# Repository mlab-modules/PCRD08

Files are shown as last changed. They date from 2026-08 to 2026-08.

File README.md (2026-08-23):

# PCRD08 - Analogue backend for SiPM detectors with scintillation crystals

Analogue front-end and ADC module for radiation detectors based on silicon photomultipliers (SiPM) coupled to scintillation crystals. The module amplifies the SiPM pulses, detects a threshold crossing, and digitizes the signal for a controlling MCU over SPI.

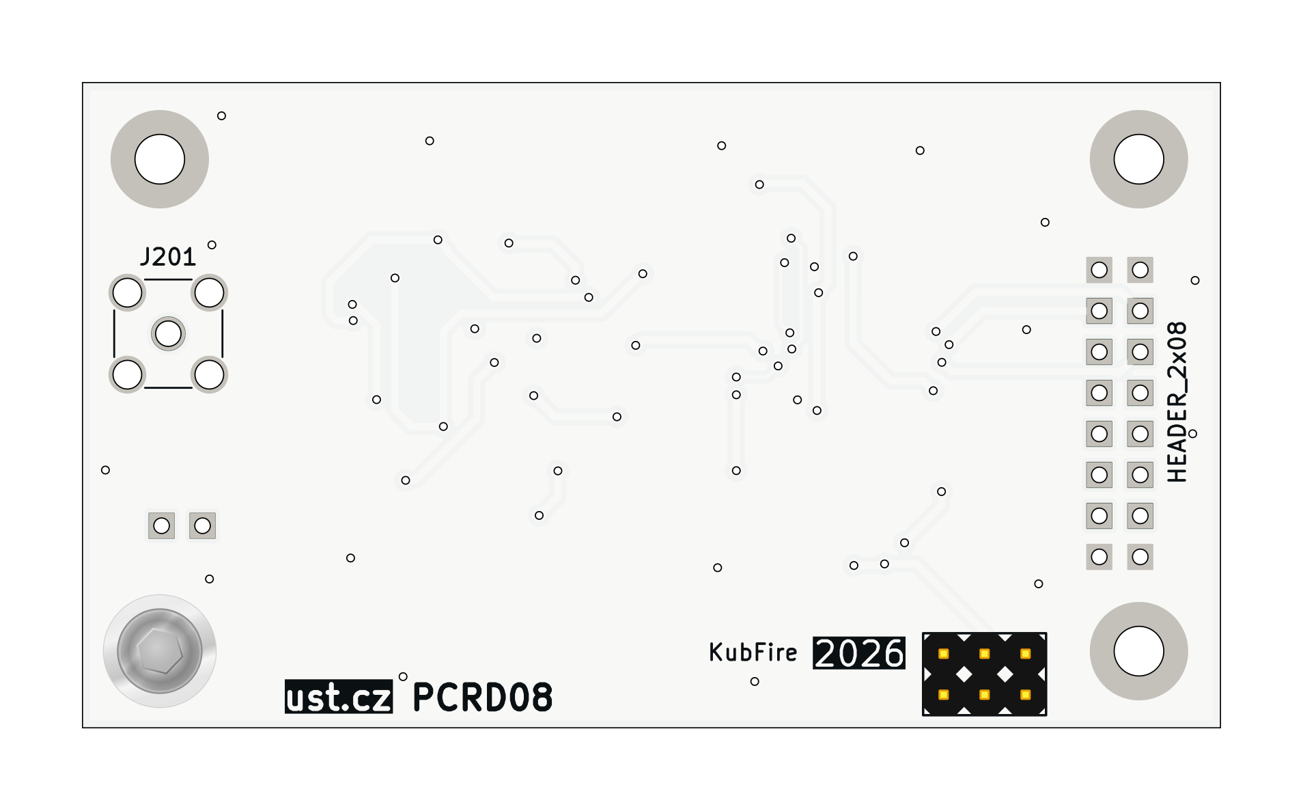
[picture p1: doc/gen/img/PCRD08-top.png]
PCRD08 Top view


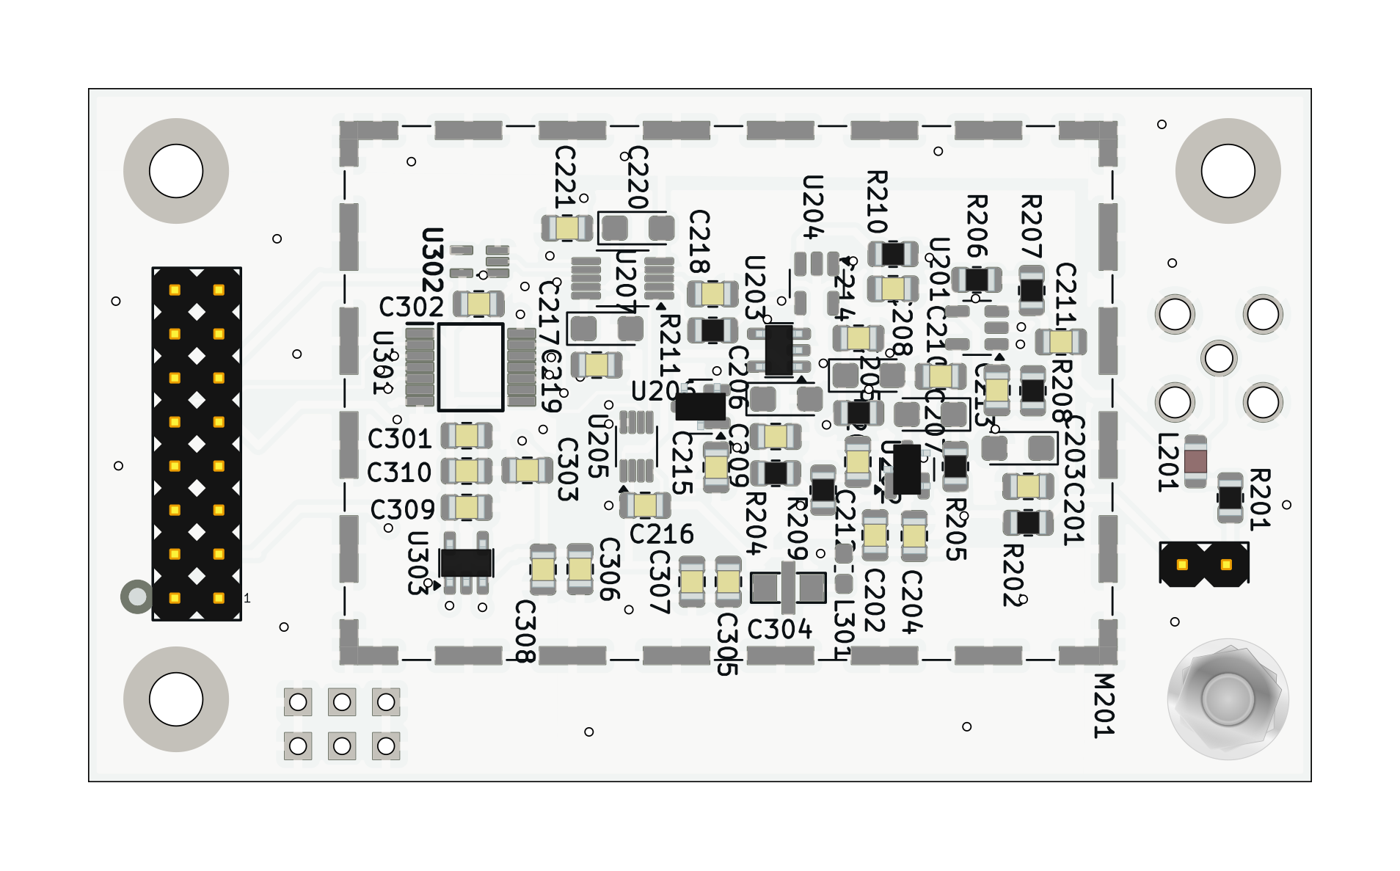
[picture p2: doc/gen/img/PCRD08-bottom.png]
PCRD08 Bottom view


### Principle of function

The detector signal enters through the MCX connector J201 and is AC-coupled into a non-inverting amplifier (U201, AD8691). A second AD8691 stage (U204) provides additional gain before the signal reaches the LTC1865-MS ADC (U207), which is read out over SPI. A comparator (U203, TS3021ILT) together with a D flip-flop (U205, SN74LVC2G74) latches a digital flag whenever the signal crosses a threshold, which the controlling MCU can use to time the ADC conversion (CONV/RST/SCK/SDI/SDO are supplied by the host over the module's socket interface).

### Difference from PCRD07

PCRD08 reuses the general architecture of the older [PCRD07](https://github.com/mlab-modules/PCRD07) analogue backend (dual AD8691 gain stages, TS3021ILT comparator, LTC1865-MS ADC), but the analogue signal processing was reworked for SiPM+scintillator pulses, which are positive-going:

- **Input polarity** - PCRD07 (both revision A and B) amplifies the input signal with an inverting first stage (signal fed into the op-amp's `-` input, gain set by the feedback/input resistor ratio). PCRD08's input stage (U201) instead feeds the signal into the op-amp's `+` input, giving a non-inverting, unity-gain-at-high-frequency response suited to positive pulses.
- **No analogue sample-and-hold switch** - PCRD07 uses an analogue switch (TS5A4594) driven by its comparator/flip-flop pair to freeze the peak voltage on a storage capacitor, i.e. a true analogue peak-detector/memory circuit. PCRD08 has no such switch or hold capacitor; its comparator/flip-flop pair (U203/U205) only produces a digital threshold-crossing flag, and the ADC conversion is triggered directly by the host rather than sampling a held analogue voltage.

(Verified by comparing `hw/sch_pcb/analogue_backend.kicad_sch` of both modules.)

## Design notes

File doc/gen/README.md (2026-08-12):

# PCB

Board size: 70.62x40.06 mm (2.78x1.58 inches)

- This is the size of the rectangle that contains the board
- Thickness: 1.6 mm (63 mils)
- Material: FR4
- Finish: HAL SnPb
- Layers: 2
- Copper thickness: 35 µm

Solder mask: TOP / BOTTOM

- Color: Green

Silk screen: TOP / BOTTOM

- Color: White

Stackup:

| Name | Type | Color | Thickness [µm]| Material | Er | Loss tan |
|---|---|---|---|---|---|---|
| F.SilkS | Top Silk Screen | | | | | |
| F.Mask | Top Solder Mask | | 10 | | | |
| F.Cu | copper | | 35 | | | |
| dielectric 1 | core | | 1510 | FR4 | 4.5 | 0.020 |
| B.Cu | copper | | 35 | | | |
| B.Mask | Bottom Solder Mask | | 10 | | | |
| B.Paste | Bottom Solder Paste  | | | | | |
| B.SilkS | Bottom Silk Screen | | | | | |

# Important sizes

Clearance: 0.2 mm (8 mils)

Track width: 0.2 mm (8 mils)

- By design rules: 0.2 mm (8 mils)

Drill: 0.5 mm (20 mils)

- Vias: 0.5 mm (20 mils) [Design: 0.4 mm (16 mils)]
- Pads: 1.0 mm (39 mils)
- The above values are real drill sizes, they add 0.1 mm (4 mils) to plated holes (PTH)

Via: 0.8/0.4 mm (31/16 mils)

- By design rules: 0.8/0.3 mm (31/12 mils)
- Micro via: yes [0.2/0.1 mm (8/4 mils)]
- Buried/blind via: yes
- Total: 58 (thru: 58 buried/blind: 0 micro: 0)

Outer Annular Ring: 0.15 mm (6 mils)

- By design rules: 0.23 mm (9 mils)

Eurocircuits class: 4B
- Using min drill 0.5 mm for an OAR of 0.15 mm

# General stats

Components count: (SMD/THT)

- Top: 0/6 (THT)
- Bottom: 56/2 (SMD + THT)

Defined tracks:

- 0.1 mm (4 mils)
- 0.2 mm (8 mils)
- 0.3 mm (12 mils)
- 0.45 mm (18 mils)
- 0.5 mm (20 mils)
- 0.6 mm (24 mils)
- 0.7 mm (28 mils)

Used tracks:

- 0.2 mm (8 mils) (82) defined: yes
- 0.45 mm (18 mils) (349) defined: yes

Defined vias:

Used vias:

- 0.8/0.4 mm (31/16 mils) (Count: 58, Aspect: 2.0 A) defined: no

Holes (excluding vias):

- 0.89 mm (35 mils) (24)
- 1.5 mm (59 mils) (1)
- 1.7 mm (67 mils) (4)
- 3.0 mm (118 mils) (4)

Oval holes:

Drill tools (including vias and computing adjusts and rounding):

- 0.5 mm (20 mils) (58)
- 1.0 mm (39 mils) (24)
- 1.6 mm (63 mils) (1)
- 1.8 mm (71 mils) (4)
- 3.1 mm (122 mils) (4)

Solder paste stats:

Using a paste with 87.75 % alloy, that has an specific gravity for the alloy of 7.4 g/cm³
and 1.0 g/cm³ for the flux. This paste has an specific gravity of  4.15 g/cm³.

The stencil thickness is  0.12 mm.

| Side | Pads with paste | Area [mm²] | Paste [g] |
|---|---|---|---|
| Total  | 184 | 265.43 | 1.32 |

Note: this is just an approximation to the theoretical value. Margins of the solder mask and waste aren't computed.

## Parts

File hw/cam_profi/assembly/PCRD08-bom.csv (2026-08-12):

Component | Description | Part | References | Value | Footprint | Quantity Per PCB | Datasheet | ust_id | ust_id2 | mf | description_1 | package | mpn | price | oc_farnell | snapeda_link | mp | supplier | oc_newark | availability | check_prices | manufacturer_name | mouser_price-stock | mouser_part_number | height | arrow_price-stock | arrow_part_number | manufacturer_part_number
1 | Unpolarized capacitor | C | C211C213C214C218 | 1nF | C_0805_2012Metric | 4 |  | 6508260b462c6d9e720541f1 651abc26462c6d9e720551fa 5c70984812875079b91f8ba6
2 | Unpolarized capacitor | C | C201C202C204C208C209C210C212C215C216C219C221C301C302C303C305C308C310 | 100nF | C_0805_2012Metric | 17 |  | 6508260b462c6d9e720541f1 5c70984712875079b91f8b4c
3 | EMI filter, single capacitor | Filter_EMI_C | C304 | 1uF | FIR_0805 | 1 | http://www.murata.com/~/media/webrenewal/support/library/catalog/products/emc/emifil/c31e.ashx?la=en-gb | 5c70984412875079b91f880f
4 | Polarized capacitor | C_Polarized | C203C205C206C207C217C220 | 10uF | CP_EIA-3216-18_Kemet-A | 6 |  | 65089dd0462c6d9e720542b3
5 | Unpolarized capacitor | C | C306C307C309 | 10uF | C_0805_2012Metric | 3 |  | 5c70984712875079b91f8b53
6 | 2x01 2.54 mm pitch header | HEADER_2x01 | J202 | HEADER_2x01 | Straight_2x01 | 1
7 | 2x03 2.54 mm pitch header | HEADER_2x03 | J301 | HEADER_2x03 | Straight_2x03 | 1
8 | 2x08 2.54 mm pitch header | HEADER_2x08 | J302 | HEADER_2x08 | Straight_2x08 | 1
9 | coaxial connector (BNC, SMA, SMB, SMC, Cinch/RCA, LEMO, ...) | Conn_Coaxial | J201 | MCX | SMA_Amphenol_901-144_Vertical | 1 | ~ | 5fa10cc512875025b39779f6
10 | Inductor | L | L201 | L | L_0805_2012Metric | 1 |  | 626fd6fcdc56076e9a222966
11 | Inductor with ferrite core, small symbol | L_Ferrite_Small | L301 | NL03KT330 | L_0603_1608Metric_Pad1.05x0.95mm_HandSolder | 1 |  | 64fe1808f3b9d36f37fc944d
12 | Two-piece EMI RF shielding cabinet | RFShield_TwoPieces | M201 | RFShield_TwoPieces | Laird_Technologies_BMI-S-210-F_44.00x30.50mm | 1 |  | 5c70984312875079b91f873d | 5c70984312875079b91f873c
13 | Resistor | R | R202R211 | 10 | R_0805_2012Metric | 2 |  | 5c70984512875079b91f896d
14 | Resistor | R | R201R203R204R205R206 | 100 | R_0805_2012Metric | 5 |  | 5c70984512875079b91f8977 5c70984512875079b91f898c
15 | Resistor | R | R209 | 470R | R_0805_2012Metric | 1 |  | 5c70984512875079b91f8986
16 | Resistor | R | R207R208 | 1k | R_0805_2012Metric | 2 |  | 5c70984512875079b91f898c 5c70984612875079b91f899f
17 | Resistor | R | R210 | 10k | R_0805_2012Metric | 1 |  | 5c70984612875079b91f899f
18 | Single Rail-to-Rail High Output Current Operational Amplifiers, SOT-23-5 | AD8691 | U201U204 | AD8691 | TSOT-23-5 | 2 | https://www.analog.com/media/en/technical-documentation/data-sheets/AD8691_8692_8694.pdf | 5d47c084128750448e6b4671
19 | 2.0V 25μA Micropower Voltage Reference, SOT-23 | ISL21070CIH320Z-TK | U206 | ISL21080CIH341Z-TK | SOT-23 | 1 | https://cz.mouser.com/datasheet/2/698/REN_isl21080_DST_20040119-1998038.pdf | 6555591d0c8d609e3e79abc1
20 | 2.0V 25μA Micropower Voltage Reference, SOT-23 | ISL21070CIH320Z-TK | U202 | ISL21080DIH309 | SOT-23 | 1 | https://www.renesas.com/us/en/document/dst/isl21080-datasheet | 5c70984712875079b91f8b0b
21 | Dual channel 16-bit SAR Analog to Digital Converter, 5V supply, 150ksps, SPI interface | LTC1865-MS | U207 | LTC1865-MS | MSOP-10_3x3mm_P0.5mm | 1 | https://www.analog.com/media/en/technical-documentation/data-sheets/18645fb.pdf | 67f14385ee7fc534862c535e
22 | 300mA Low-dropout Voltage Regulator, Vout 3.3V, Vin up to 5.5V, SOT-23 | MIC5504-3.3YM5 | U303 | MIC5504-3.3YM5-TR | SOT-23-5 | 1 | http://ww1.microchip.com/downloads/en/DeviceDoc/MIC550X.pdf | 5c7255e81287500b4e112ea2
23 |  | SN74LVC1G125DCKT | U302 | SN74LVC1G125DCKT | SOT65P210X110-5N | 1 |  |  |  | Texas Instruments | Buffer, Non-Inverting 1 Element 1 Bit per Element 3-State Output SC-70-5 | SC70-5 | SN74LVC1G125DCKT | None | 1470733 | https://www.snapeda.com/parts/SN74LVC1G125DCK/Texas+Instruments/view-part/?ref=snap | SN74LVC1G125DCK | Texas Instruments | 22H0380 | In Stock | https://www.snapeda.com/parts/SN74LVC1G125DCK/Texas+Instruments/view-part/?ref=eda
24 | 74AUC1G74, Single D Flip-Flop, Low-Voltage CMOS | 74LVC2G74 | U205 | SN74LVC2G74 | VSSOP-8_2.3x2mm_P0.5mm | 1 | https://www.ti.com/lit/ds/symlink/sn74lvc2g74-ep.pdf | 65555d4795a79cc5ac409b41
25 | Single Rail-to-Rail High Output Current Operational Amplifiers, SOT-23-5 | AD8691 | U203 | TS3021ILT | SOT-23-5 | 1 | https://www.st.com/resource/en/datasheet/ts3021.pdf | 5d47bfd4128750448e6b465e
26 | Translation - Voltage Levels Four channel unidirectional level shifter | TXU0304PWR | U301 | TXU0304PWR | SOP65P640X120-14N | 1 |  |  |  | Texas Instruments | Four-channel fixed multidirectional level shifter | None |  | None |  | https://www.snapeda.com/parts/TXU0304PWR/Texas+Instruments/view-part/?ref=snap | TXU0304PWR |  |  | In Stock | https://www.snapeda.com/parts/TXU0304PWR/Texas+Instruments/view-part/?ref=eda | Texas Instruments | https://www.mouser.co.uk/ProductDetail/Texas-Instruments/TXU0304PWR?qs=QNEnbhJQKvZVYXIKZoXs0A%3D%3D | 595-TXU0304PWR | 1.2mm | https://www.arrow.com/en/products/txu0304pwr/texas-instruments?utm_currency=USD&region=nac | TXU0304PWR | TXU0304PWR

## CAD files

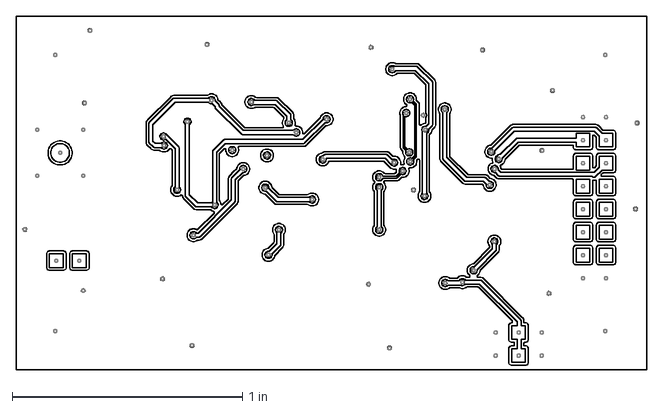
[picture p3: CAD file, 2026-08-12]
doc/gen/dxf/PCRD08-F_Cu.dxf
2.74 x 1.54 in

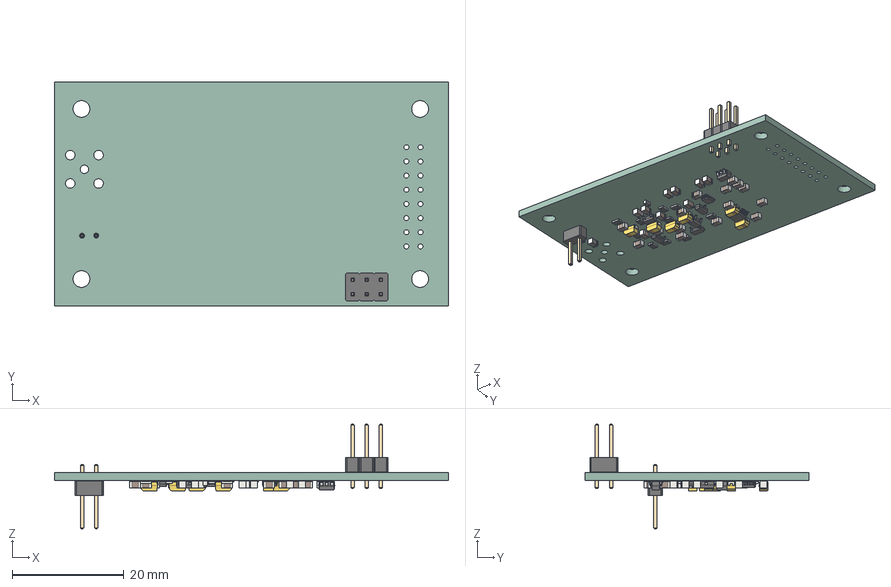
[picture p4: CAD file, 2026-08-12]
doc/gen/PCRD08.step
70.6 x 40.1 x 18.8 mm
PinHeader_2x03_P254mm_Vertical
C_0805_2012Metric x 24
R_0805_2012Metric x 11
SOT-23-5 x 2
TSOT-23-5 x 2
MSOP-10_3x3mm_P0.5mm
SOT-23 x 2
CP_EIA_3216_18_Kemet_A x 6
L_0805_2012Metric
VSSOP-8_2.3x2mm_P0.5mm
L_0603_1608Metric
PinHeader_2x01_P254mm_Vertical
kibot_w9a66jc2_PCB

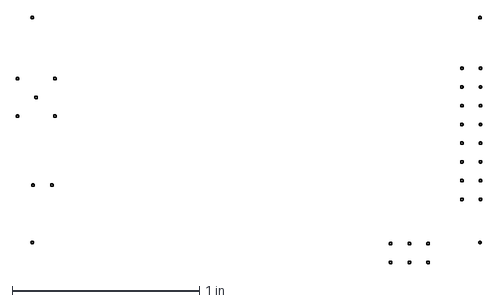
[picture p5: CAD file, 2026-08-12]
doc/gen/dxf/PCRD08-Margin.dxf
2.49 x 1.32 in

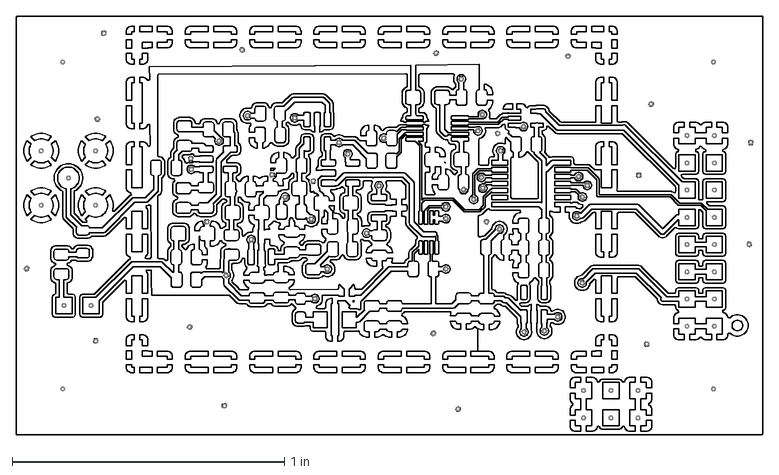
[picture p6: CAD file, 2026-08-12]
doc/gen/dxf/PCRD08-B_Cu.dxf
2.74 x 1.54 in

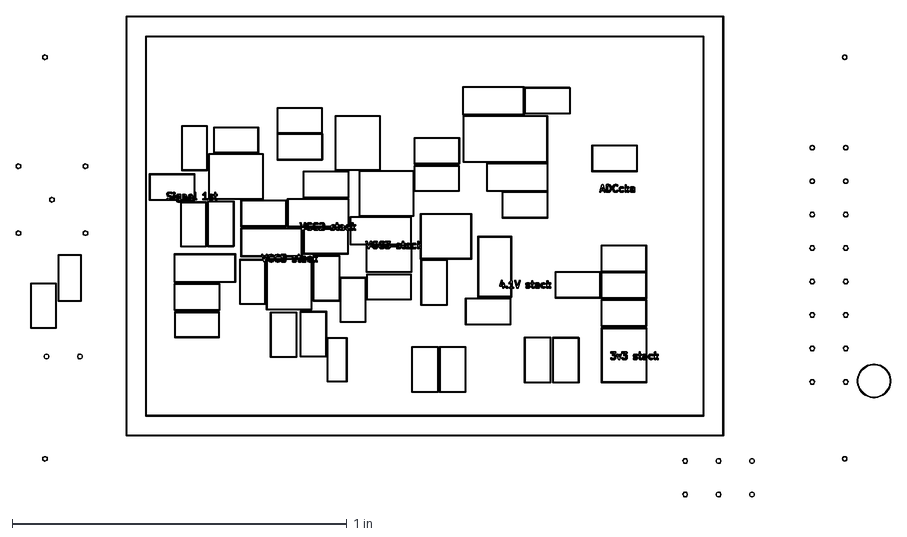
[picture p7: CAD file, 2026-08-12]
doc/gen/dxf/PCRD08-B_Courtyard.dxf
2.61 x 1.44 in

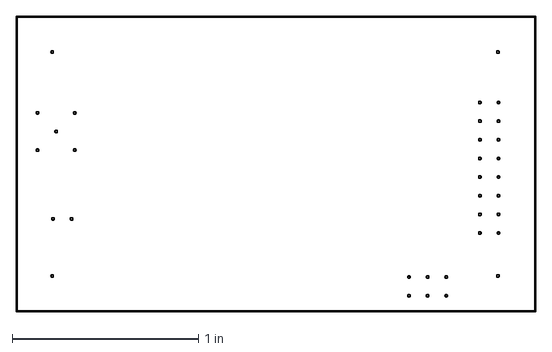
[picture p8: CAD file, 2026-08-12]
doc/gen/dxf/PCRD08-Edge_Cuts.dxf
2.79 x 1.58 in

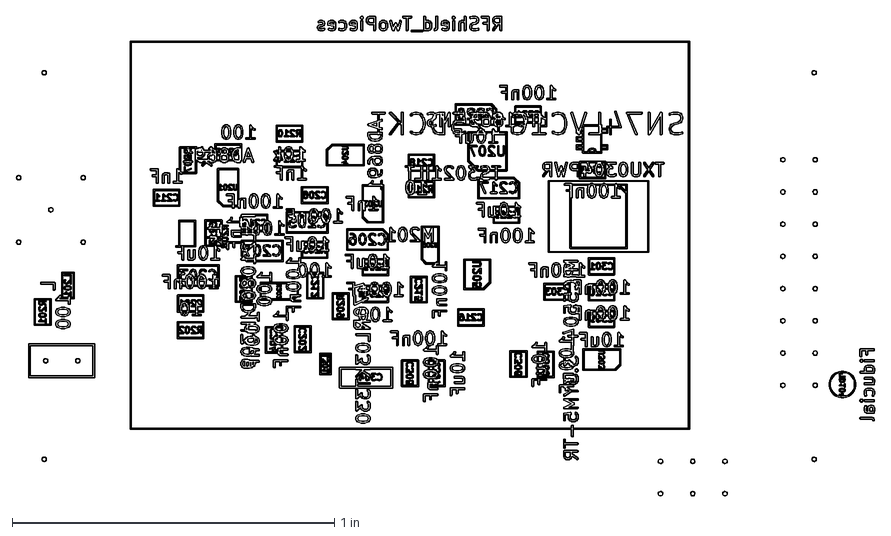
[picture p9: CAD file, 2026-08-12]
doc/gen/dxf/PCRD08-B_Fab.dxf
2.66 x 1.49 in

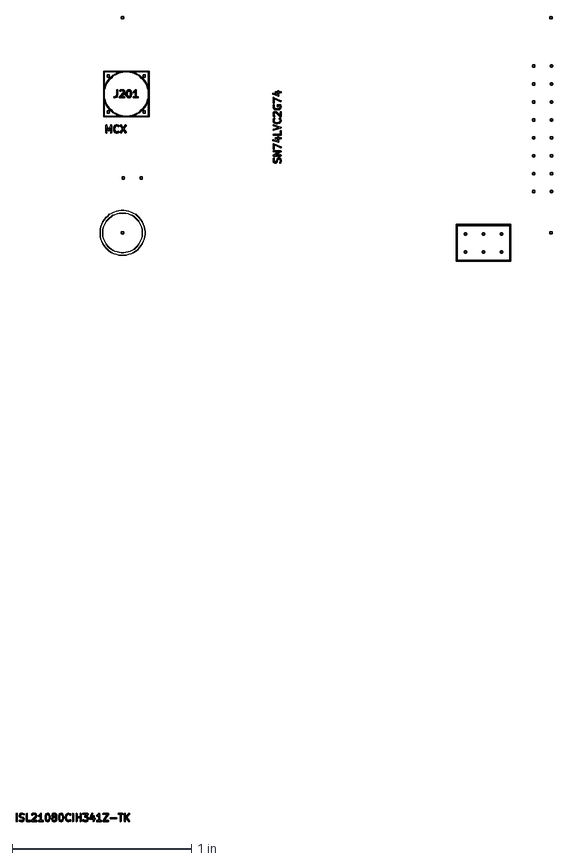
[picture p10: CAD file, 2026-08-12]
doc/gen/dxf/PCRD08-F_Fab.dxf
2.99 x 4.49 in

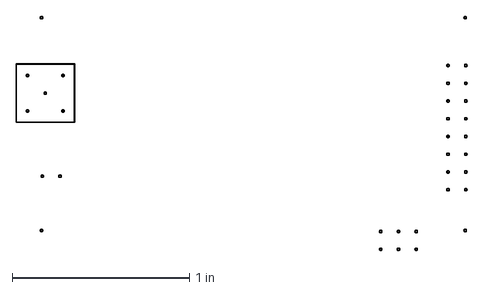
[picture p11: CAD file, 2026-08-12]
doc/gen/dxf/PCRD08-F_Courtyard.dxf
2.54 x 1.32 in

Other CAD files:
doc/gen/dxf/PCRD08-B_Mask.dxf
doc/gen/dxf/PCRD08-B_Paste.dxf
doc/gen/dxf/PCRD08-B_Silkscreen.dxf
doc/gen/dxf/PCRD08-F_Mask.dxf
doc/gen/dxf/PCRD08-F_Silkscreen.dxf

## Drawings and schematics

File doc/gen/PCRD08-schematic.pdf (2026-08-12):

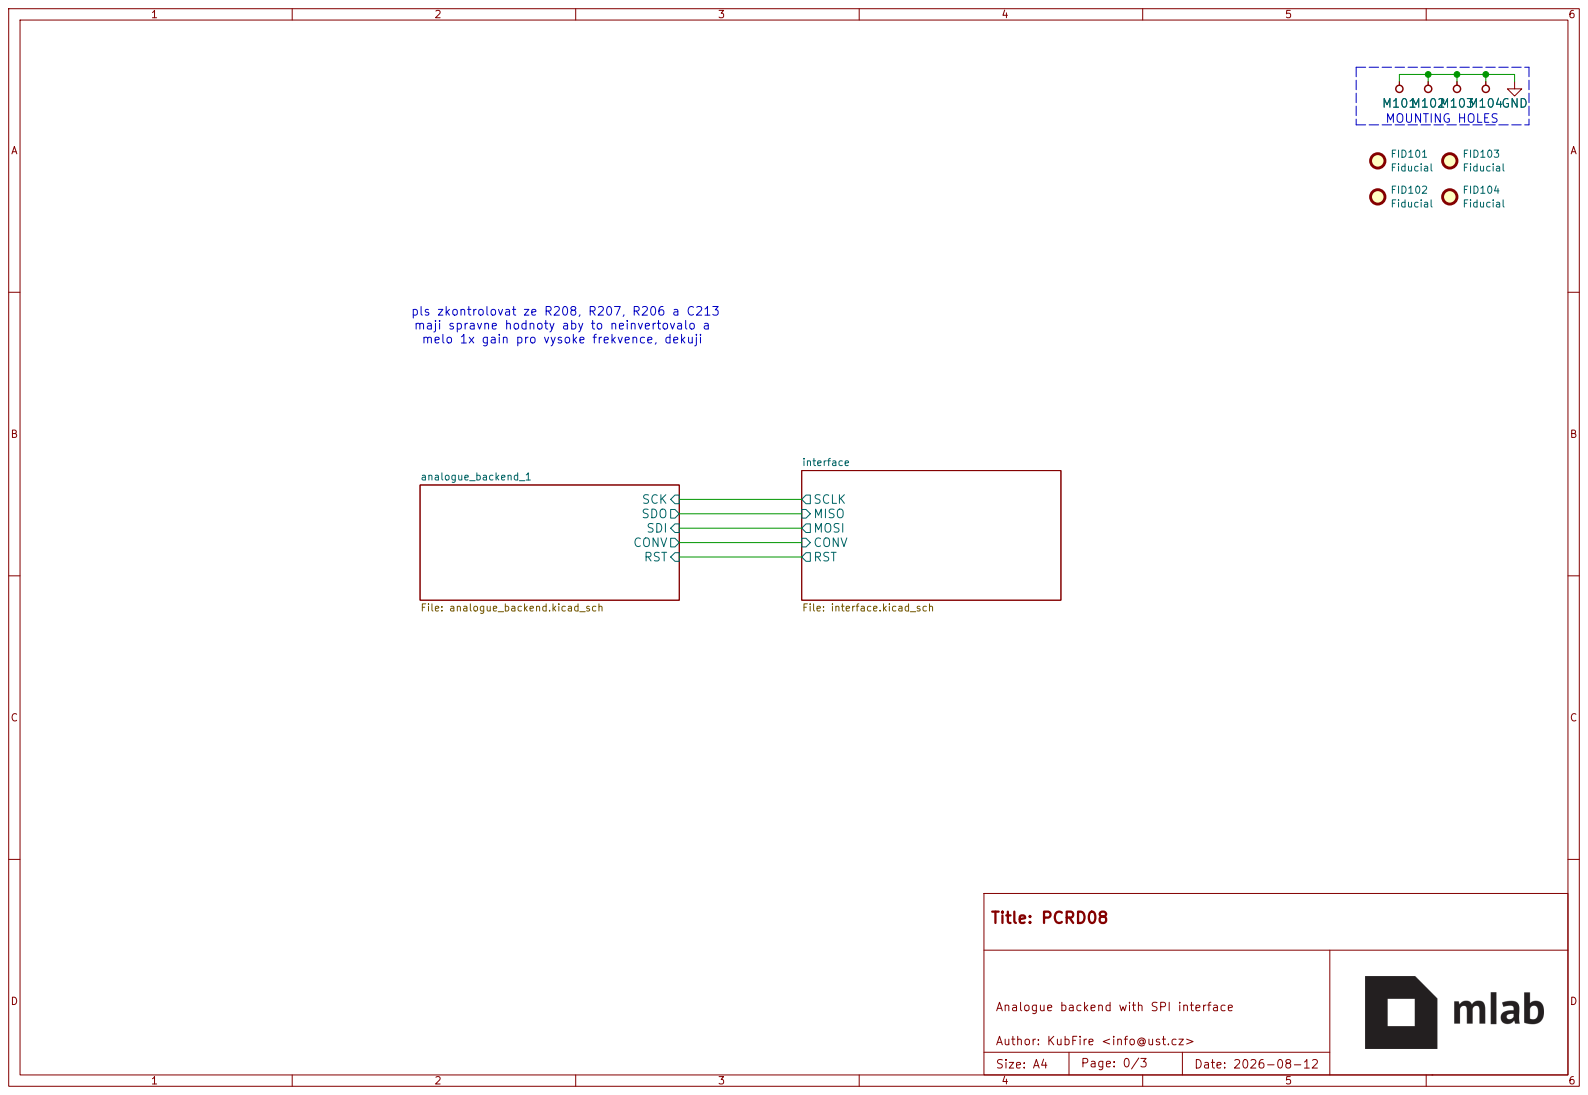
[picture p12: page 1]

pls zkontrolovat ze R208, R207, R206 a C213
maji spravne hodnoty aby to neinvertovalo a melo 1x gain pro vysoke frekvence, dekuji

Analogue backend with SPI interface Author: KubFire <info@ust.cz>

Size: A4 | Page: 0/3 | Date: 2026-08-12

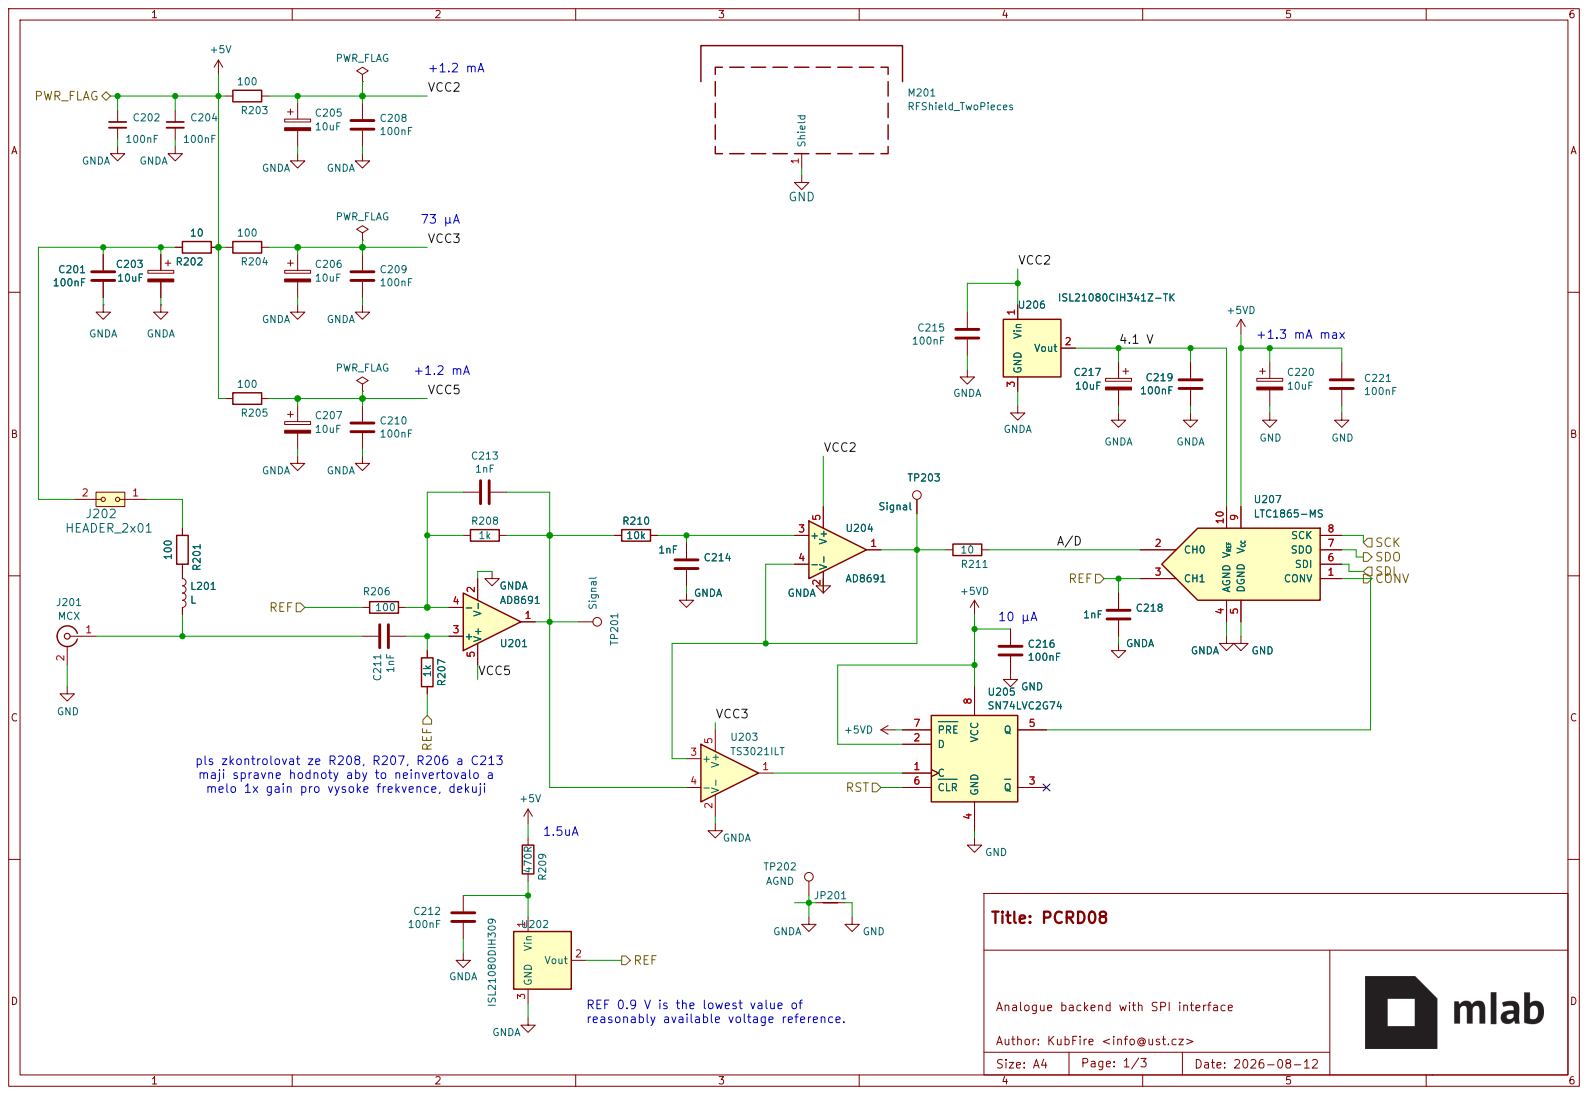
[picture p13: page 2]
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

REF 0.9 V is the lowest value of
reasonably available voltage reference.

Analogue backend with SPI interface Author: KubFire <info@ust.cz>

Size: A4 | Page: 1/3 | Date: 2026-08-12

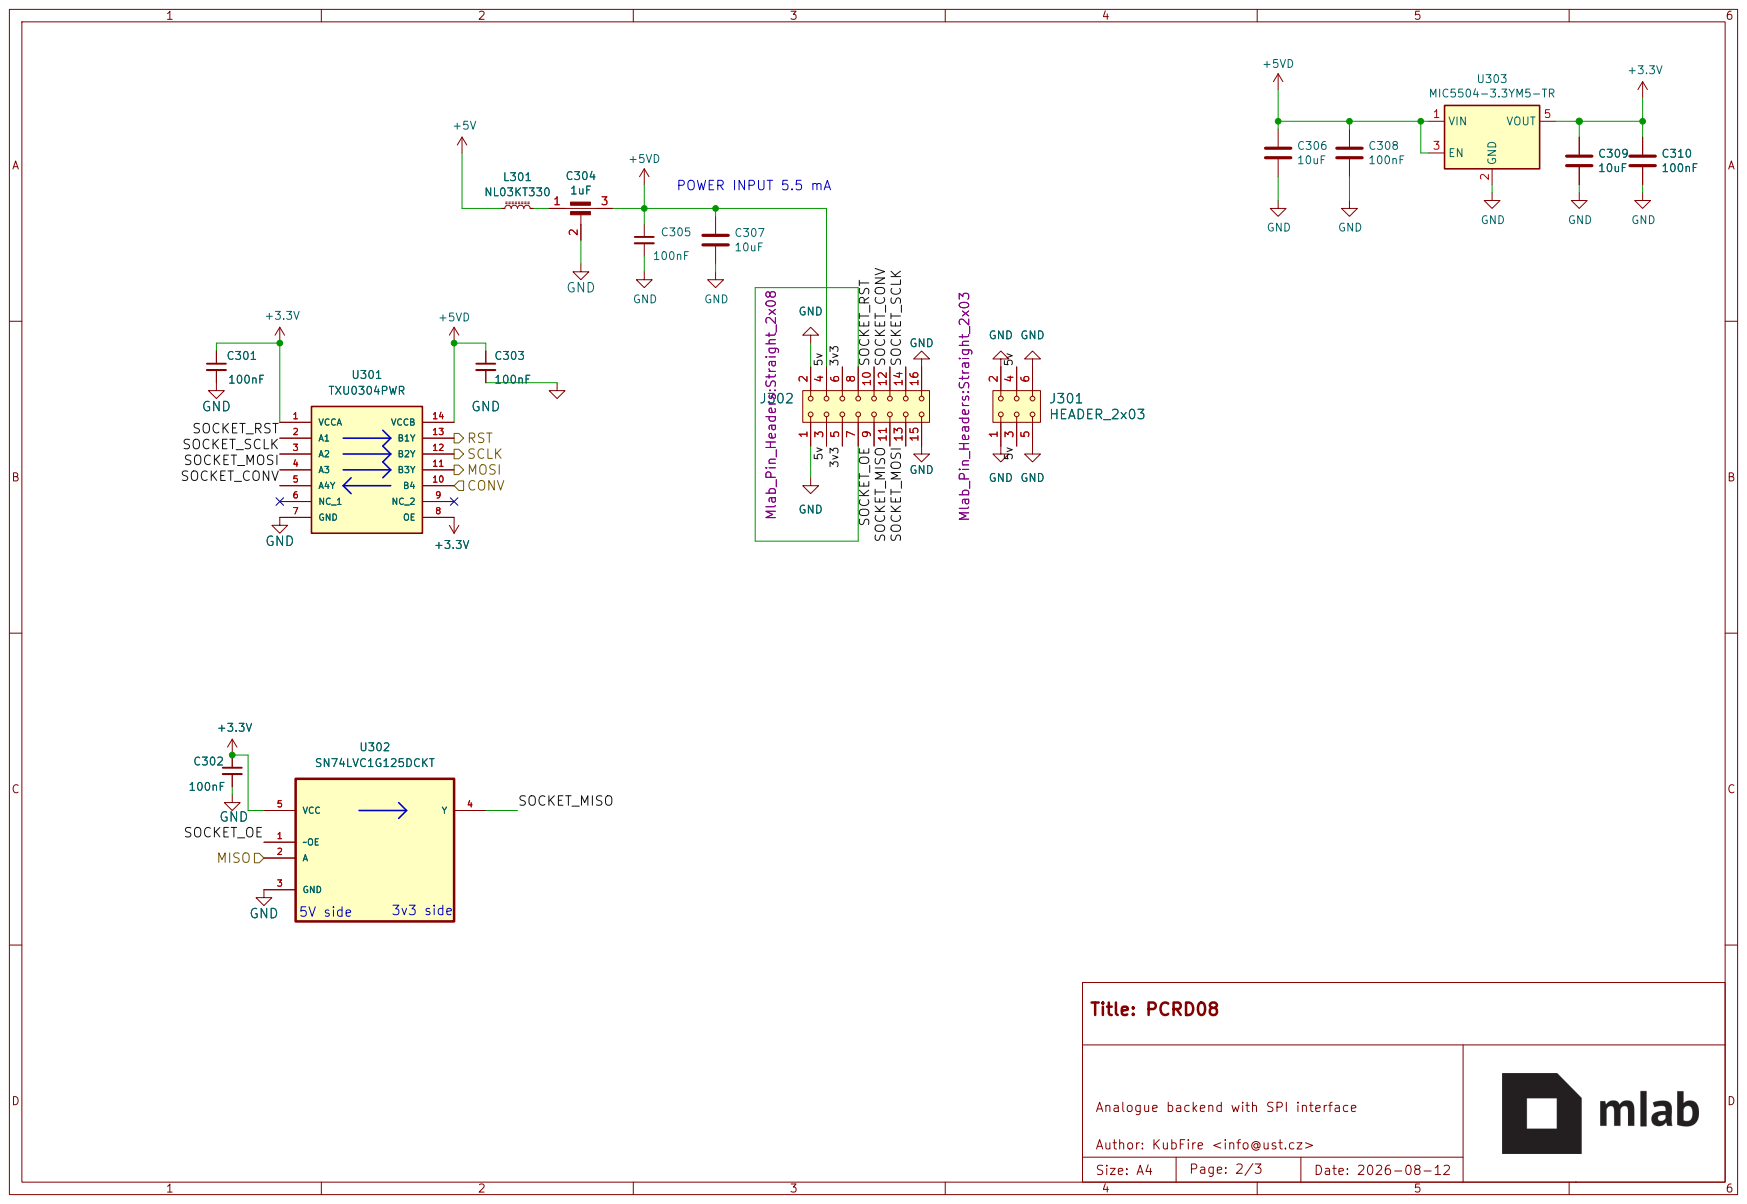
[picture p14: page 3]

Analogue backend with SPI interface Author: KubFire <info@ust.cz>

Size: A4 | Page: 2/3 | Date: 2026-08-12

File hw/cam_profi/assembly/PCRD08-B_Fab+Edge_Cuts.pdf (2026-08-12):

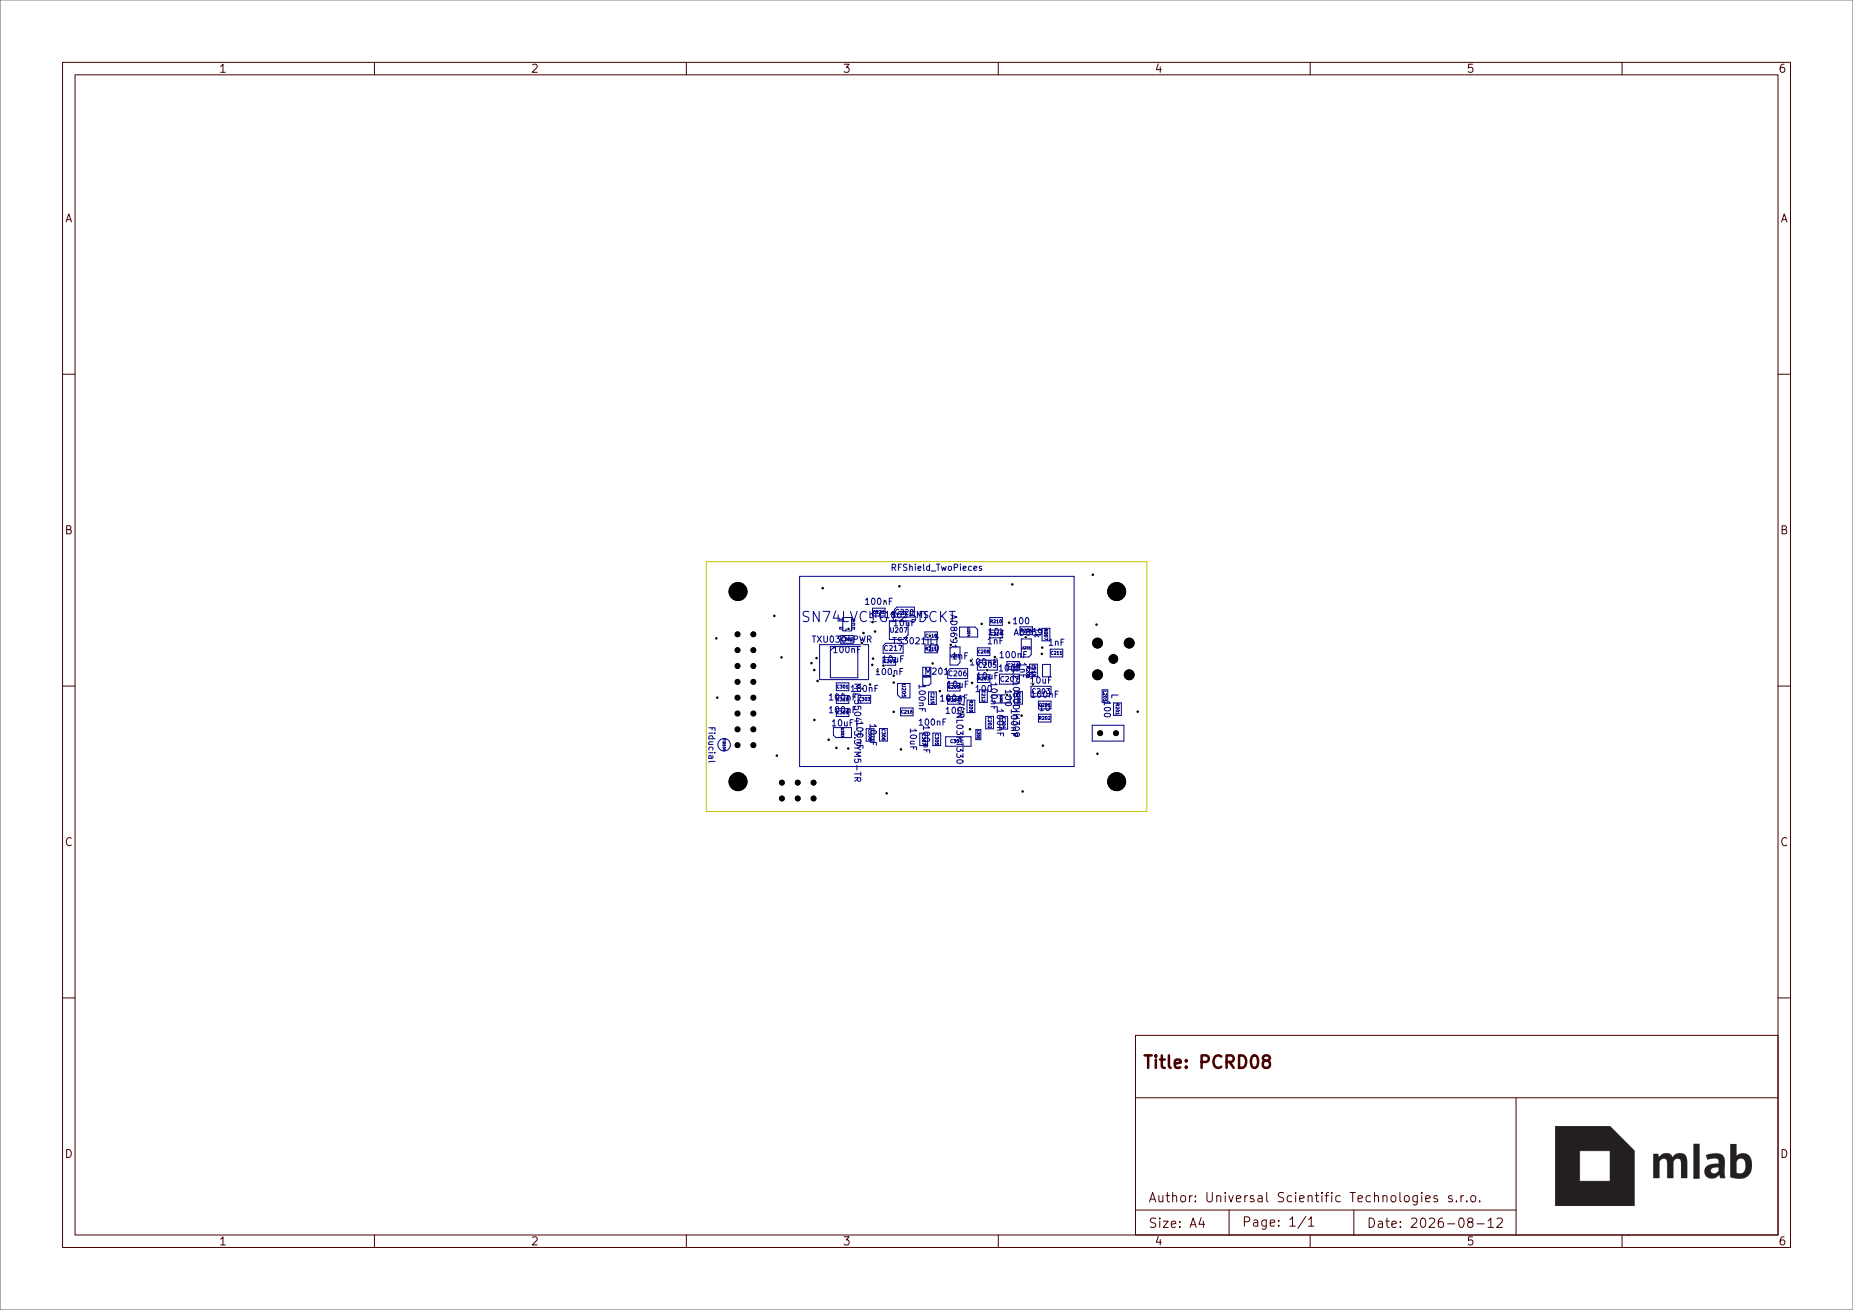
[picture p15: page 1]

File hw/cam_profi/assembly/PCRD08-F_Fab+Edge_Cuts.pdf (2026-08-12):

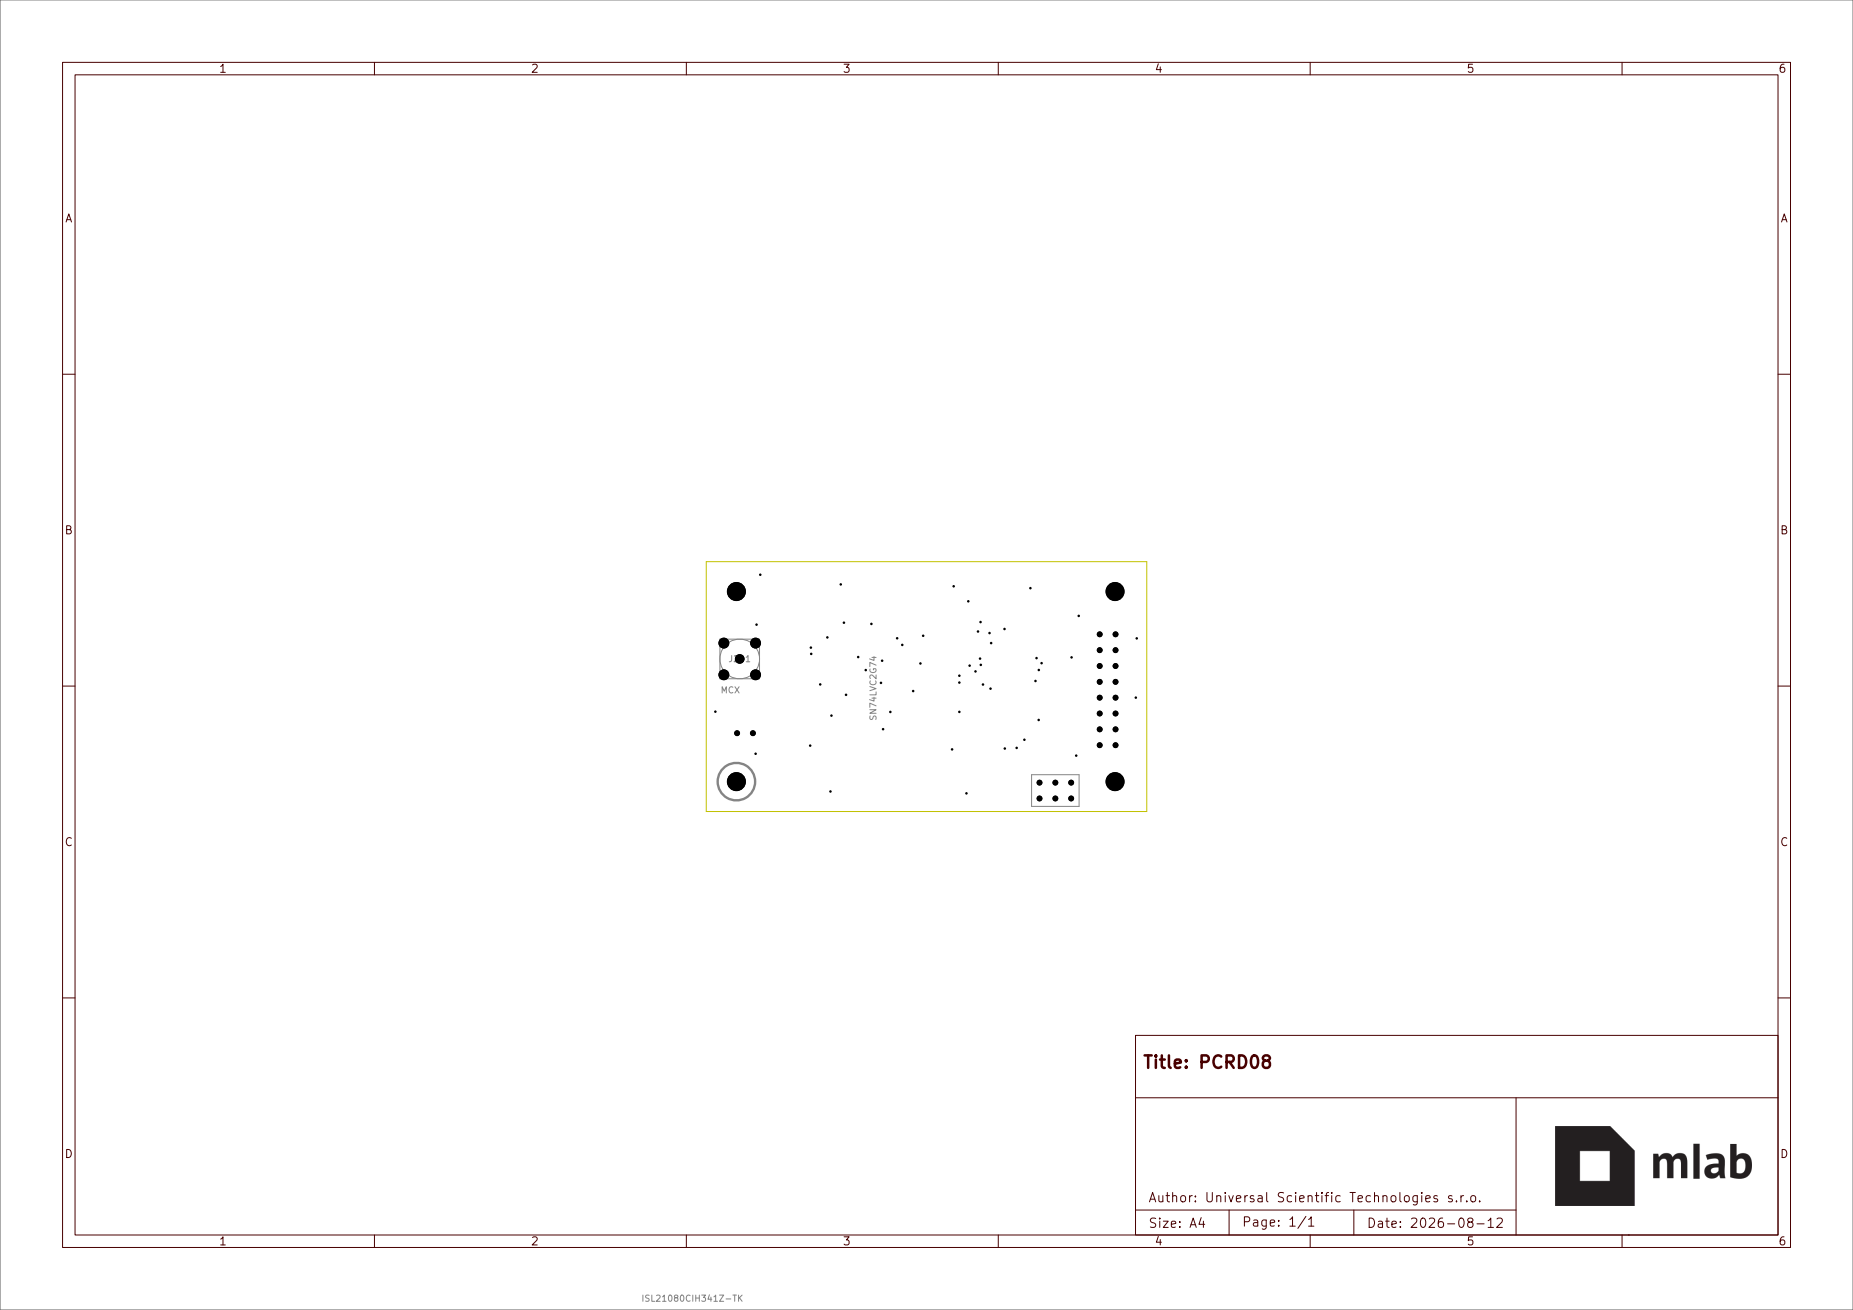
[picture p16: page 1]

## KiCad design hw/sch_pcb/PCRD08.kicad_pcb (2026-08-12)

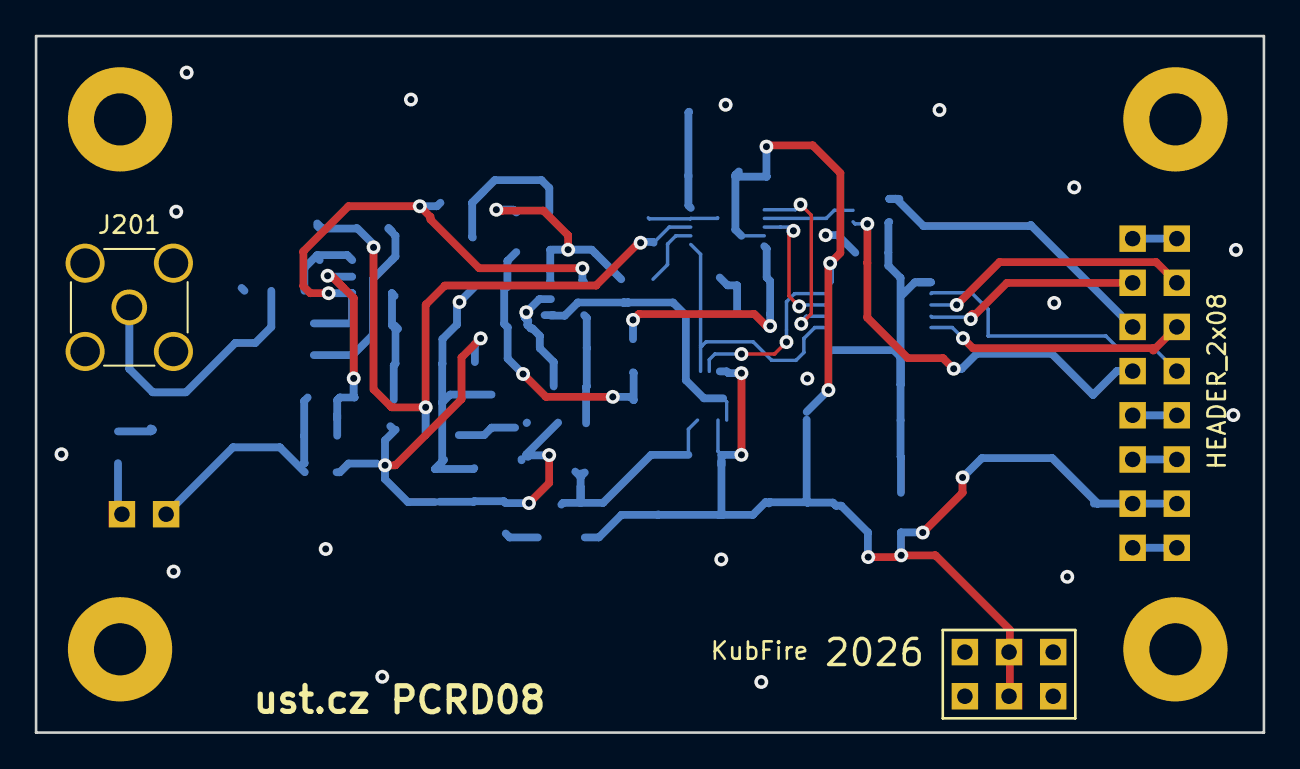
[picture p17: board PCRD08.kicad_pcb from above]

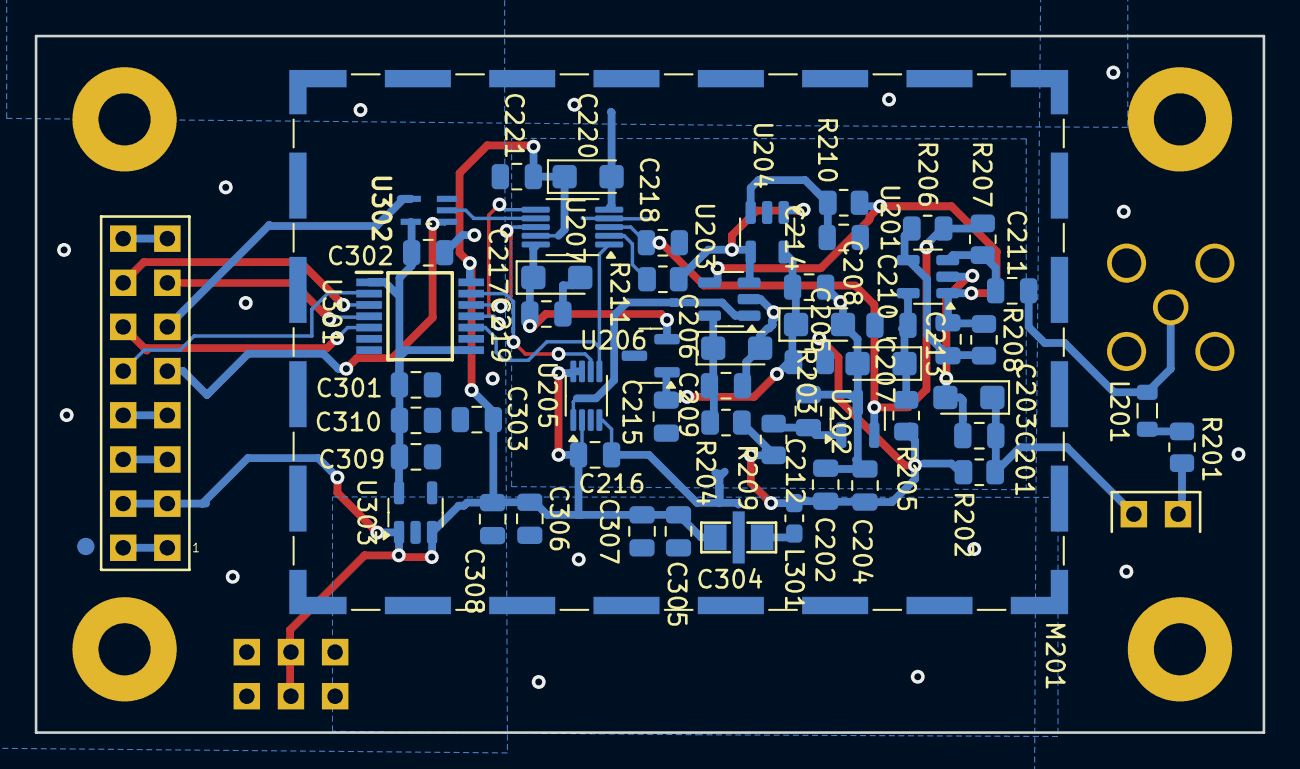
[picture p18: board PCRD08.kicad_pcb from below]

Board: 2 copper layers, 70.6 x 40.1 mm, 62 parts (59 on the bottom side), 36 nets.

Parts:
C201, C202, C204, C208, C209, C210, C212, C215, C216, C219, C221, C301, C302, C303, C305, C308, C310: 100nF; C_0805_2012Metric
C203, C205, C206, C207, C217, C220: 10uF; CP_EIA-3216-18_Kemet-A
C211, C213, C214, C218: 1nF; C_0805_2012Metric
C304: 1uF; FIR_0805
C306, C307, C309: 10uF; C_0805_2012Metric
FID104: Fiducial; Fiducial_1mm_Mask2mm
J201: MCX; SMA_Amphenol_901-144_Vertical
J202: HEADER_2x01; Straight_2x01
J301: HEADER_2x03; Straight_2x03
J302: HEADER_2x08; Straight_2x08
JP201: Jumper_2_Bridged; NetTie-2_SMD_Pad0.5mm
L201: L; L_0805_2012Metric
L301: NL03KT330; L_0603_1608Metric_Pad1.05x0.95mm_HandSolder
M103: HOLE; MountingHole_3mm
M201: RFShield_TwoPieces; Laird_Technologies_BMI-S-210-F_44.00x30.50mm
R201, R203, R204, R205, R206: 100; R_0805_2012Metric
R202, R211: 10; R_0805_2012Metric
R207, R208: 1k; R_0805_2012Metric
R209: 470R; R_0805_2012Metric
R210: 10k; R_0805_2012Metric
U201, U204: AD8691; TSOT-23-5
U202: ISL21080DIH309; SOT-23
U203: TS3021ILT; SOT-23-5
U205: SN74LVC2G74; VSSOP-8_2.3x2mm_P0.5mm
U206: ISL21080CIH341Z-TK; SOT-23
U207: LTC1865-MS; MSOP-10_3x3mm_P0.5mm
U301: TXU0304PWR; SOP65P640X120-14N
U302: SN74LVC1G125DCKT; SOT65P210X110-5N
U303: MIC5504-3.3YM5-TR; SOT-23-5

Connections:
+3.3V: C301.1, C302.1, C309.1, C310.1, U301.1 (VCCA), U301.8 (OE), U302.5 (VCC), U303.5 (VOUT)
+5V: C202.1, C204.1, L301.1, R202.2, R203.2, R204.2, R205.2, R209.2
+5VD: C216.1, C220.1, C221.1, C303.1, C304.3, C305.1, C306.1, C307.1, C308.1, J301.3, J301.4, J302.3, J302.4, U205.2 (D), U205.7 (~PRE), U205.8 (VCC), U207.9 (V_{CC}), U301.14 (VCCB), U303.1 (VIN), U303.3 (EN)
/analogue_backend_1/4.1 V: C217.1, C219.1, U206.2 (Vout), U207.10 (V_{REF})
/analogue_backend_1/A/D: R211.1, U207.2 (CH0)
/analogue_backend_1/CONV: U205.5 (Q), U207.1 (CONV), U301.10 (B4)
/analogue_backend_1/REF: C218.1, R206.1, R207.1, U202.2 (Vout), U207.3 (CH1)
/analogue_backend_1/RST: U205.6 (~CLR), U301.13 (B1Y)
/analogue_backend_1/SCK: U207.8 (SCK), U301.12 (B2Y)
/analogue_backend_1/SDI: U207.6 (SDI), U301.11 (B3Y)
/analogue_backend_1/SDO: U207.7 (SDO), U302.2 (A)
/analogue_backend_1/VCC2: C205.1, C208.1, C215.1, R203.1, U204.5 (V+), U206.1 (Vin)
/analogue_backend_1/VCC3: C206.1, C209.1, R204.1, U203.5 (V+)
/analogue_backend_1/VCC5: C207.1, C210.1, R205.1, U201.5 (V+)
/interface/3v3: J302.5, J302.6
/interface/SOCKET_CONV: J302.12, U301.5 (A4Y)
/interface/SOCKET_MISO: J302.11, U302.4 (Y)
/interface/SOCKET_MOSI: J302.13, U301.4 (A3)
/interface/SOCKET_OE: J302.9, U302.1 (~OE)
/interface/SOCKET_RST: J302.10, U301.2 (A1)
/interface/SOCKET_SCLK: J302.14, U301.3 (A2)
GND: C216.2, C220.2, C221.2, C301.2, C302.2, C303.2, C304.2, C305.2, C306.2, C307.2, C308.2, C309.2, C310.2, J201.2 (Ext), J301.1, J301.2, J301.5, J301.6, J302.1, J302.2, J302.15, J302.16, JP201.2, M103.1, M201.1 (Shield), U205.4 (GND), U207.5 (DGND), U301.7 (GND), U302.3 (GND), U303.2 (GND)
GNDA: C201.2, C202.2, C203.2, C204.2, C205.2, C206.2, C207.2, C208.2, C209.2, C210.2, C212.2, C214.2, C215.2, C217.2, C218.2, C219.2, JP201.1, U201.2 (V-), U202.3 (GND), U203.2 (V-), U204.2 (V-), U206.3 (GND), U207.4 (AGND)
unnamed: C201.1, C203.1, J202.2, R202.1
unnamed: C304.1, L301.2
unnamed: C211.1, J201.1 (In), L201.2
unnamed: J202.1, R201.2
unnamed: J302.7, J302.8
unnamed: L201.1, R201.1
unnamed: C211.2, R207.2, U201.3 (+)
unnamed: C213.2, R206.2, R208.2, U201.4 (-)
unnamed: C212.1, R209.1, U202.1 (Vin)
unnamed: R211.2, U203.3 (+), U204.1, U204.4 (-)
unnamed: C213.1, R208.1, R210.2, U201.1, U203.4 (-)
unnamed: C214.1, R210.1, U204.3 (+)
unnamed: U203.1, U205.1 (C)

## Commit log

2026-07-30 pridan jeden txt komentar k U201 komponentu
    zadost o zkontrolovani vypoctu pro supporting rezistory a kapacitory. at to neni zkoněný
    [analogue_backend.kicad_sch, interface.kicad_sch]
2026-08-12 Rename project PCRD008 -> PCRD08 to match MLAB module naming convention
    [PCRD08.kicad_pcb, PCRD08.kicad_sch, analogue_backend.kicad_sch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]
2026-08-12 Update submodule and workflow.
    [PCRD08.kicad_pcb, PCRD08.kicad_sch, analogue_backend.kicad_sch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]
2026-08-12 Automatic update of KiCAD outputs
    [PCRD08-B_Courtyard.dxf, PCRD08-B_Cu.dxf, PCRD08-B_Fab.dxf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]
2026-08-15 Remove resolved TODO notes on R206/R207/R208/C213 gain check
    Verified U201 AC-coupled non-inverting stage: signal path enters the
    + input via C211, so it cannot invert, and the R206/R207/R208/C213
    network algebraically settles to unity gain at high frequency
    regardless of exact values (confirmed numerically with the populated
    values: phase stays within ±90°, |H|→1 above ~10 MHz).
    [PCRD08.kicad_sch, analogue_backend.kicad_sch]
2026-08-23 Re-anotate schematics.
    [PCRD08.kicad_sch, analogue_backend.kicad_sch, interface.kicad_sch]

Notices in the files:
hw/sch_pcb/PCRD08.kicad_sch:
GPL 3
